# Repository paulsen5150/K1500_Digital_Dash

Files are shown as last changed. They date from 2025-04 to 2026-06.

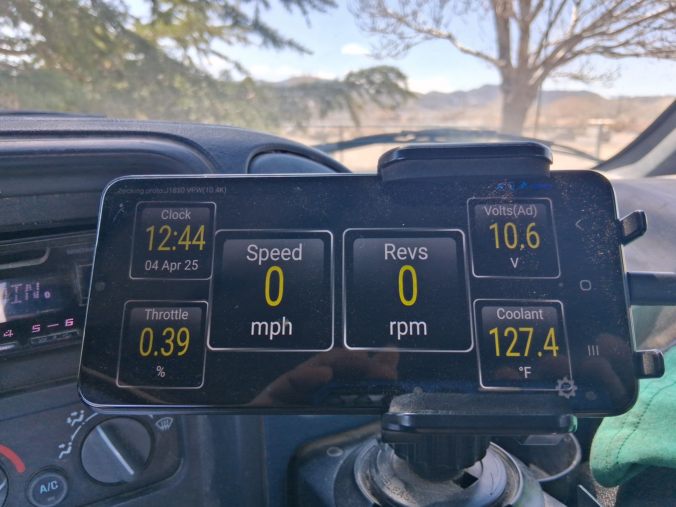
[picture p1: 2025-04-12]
Images/20250404_124431.jpg

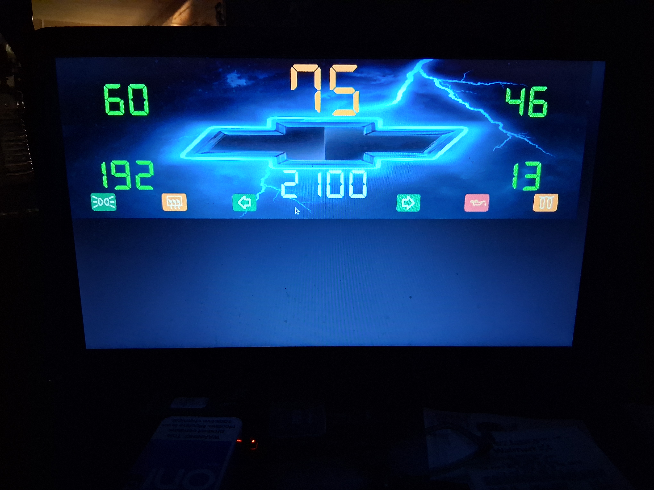
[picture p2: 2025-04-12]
Images/20250406_003022.jpg

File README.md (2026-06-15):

# KITT Master Design Document
## Revision 2.0

### Project
K1500 Integrated Truck Technology (KITT)

Vehicle: 1996 Chevrolet K1500 Extended Cab
Owner: Michael Paulsen

# Executive Summary

KITT is a long-term modernization effort transforming a 1996 Chevrolet K1500 into a modular software-defined vehicle platform. The project centers around an ESP32-S3 vehicle interface controller, an Orange Pi 5 Plus vehicle control computer, a 12.3-inch digital instrument cluster, a future center touchscreen display, advanced diagnostics, HVAC automation, multimedia integration, and a future offline AI assistant.

# System Architecture

Vehicle Interface Layer
- ESP32-S3 DevKitC-1 N16
- ADS1115
- MCP23017
- FRAM
- PC837 Optocouplers

Vehicle Control Layer
- Orange Pi 5 Plus (Confirmed)

Human Interface Layer
- 12.3-inch Digital Instrument Cluster
- 10-inch Center Touchscreen (Under Evaluation)
- Voice Interface

# Dashboard System

Primary Display
- 12.3-inch LCD instrument cluster
- Speedometer
- Tachometer
- Fuel
- Oil Pressure
- Coolant Temperature
- Warnings
- Vehicle Status

Future Center Display
- HVAC
- Navigation
- Audio
- Diagnostics
- Camera Views
- AI Interaction

# Communications Architecture

Priority Order
1. Ethernet (Preferred)
2. Isolated CANBUS (Under Evaluation)
3. USB Serial (Fallback)
4. WiFi (Testing/Beta Only)

WiFi is presently used as an electrical isolation layer during development to protect the SBC from prototype hardware faults.

# Sensor Systems

Analog Inputs
- Fuel Level
- Engine Coolant Temperature
- Oil Pressure

Digital Inputs
- Left Turn
- Right Turn
- High Beam
- Fog Lamps
- Brake Warning
- Check Engine
- Alternator Warning
- Oil Warning
- Illumination

Pulse Inputs
- Vehicle Speed Sensor
- Tachometer

# Odometer System

Status: Implemented

Storage Medium
- FRAM

Method
- 400 VSS Pulses = 0.1 Mile

# HVAC System

Confirmed Hardware
- SyRen 50 Motor Controller

Planned Sensors
- Cabin Temperature
- Ambient Temperature
- Evaporator Temperature

# Audio System

Objectives
- DSP Processing
- Voice Feedback
- Navigation Prompts
- Vehicle Alerts
- 4.1 Channel System

# Camera System

Current
- Rear Camera Planning

Future
- 360 Degree Camera System
- Bird's Eye View
- Parking Assistance
- Trailer Hookup Assistance

# Artificial Intelligence System

Objectives
- Voice-First Vehicle Operation
- Diagnostics
- Navigation
- HVAC Control
- Audio Control
- Predictive Maintenance

Historical Data Analysis
The AI will compare current operating conditions against historical baselines to identify abnormal trends and developing faults.

# Confirmed Hardware

- ESP32-S3 DevKitC-1 N16
- Orange Pi 5 Plus
- ADS1115
- MCP23017
- FRAM
- PC837 Optocouplers
- SyRen 50

# Hardware Under Evaluation

- 10-inch Center Touchscreen
- CANBUS Communications
- Final Connector System
- Final Audio Hardware
- 360 Degree Camera System

# Rejected Hardware / Approaches

- Raspberry Pi as Primary SBC
- WiFi as Permanent Communications Backbone
- Fully Isolated Analog Ground Architecture

# Development Status

Implemented
- Interface PCB
- FRAM Integration
- VSS Hardware
- Tach Hardware
- Sensor Acquisition

In Progress
- Firmware Debugging
- Communications Testing
- Dashboard Software

# Documentation Policy

Authoritative Project File:
KITT_Master_Design_Document.md

Update When:
- Hardware selected
- Hardware rejected
- Architecture changes
- Major features added
- Milestones completed

Revision Format:
v2.0 Initial Master Document
v2.1 Orange Pi Confirmed
v2.2 CANBUS Added
v2.3 Center Display Selected

# Vision Statement

Create a reliable, modular, expandable vehicle computing platform capable of evolving for years while preserving the character and serviceability of the 1996 Chevrolet K1500.

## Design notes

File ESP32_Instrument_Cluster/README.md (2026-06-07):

# ESP32 Instrument Cluster

CircuitPython digital instrument cluster for the ESP32-S3 K1500/KITT interface.

Copy `code.py` to the CircuitPython board root as `code.py`.

## Maintenance Rule

For every future change to `code.py`, add one short dated sentence to the
`# Change log:` block at the top of `code.py` before committing.

## Main Screen

- Landscape 320x240 ST7789 layout
- Large digital MPH and RPM
- Fuel, coolant temp, oil pressure, PRNDL
- Indicator/warning lamp rows
- Bottom-center digital odometer

The page button cycles from the cluster screen to diagnostic pages for
indicators, analog inputs, VSS/tach/odometer, and system status.

## Important Constants

At the top of `code.py`:

- `VSS_PULSES_PER_MILE = 4000`
- `VSS_PULSES_PER_TENTH_MILE = 400`
- `TACH_PULSES_PER_REV = 2.0`
- `ODOMETER_START_TENTHS = 2530000`
- `ODOMETER_START_REMAINDER_PULSES = 0`
- `ODOMETER_SAVE_INTERVAL_SECONDS = 60.0`

The analog sender conversions are placeholders and should be adjusted after
bench or vehicle testing.

## Odometer Storage

The odometer is stored in the MB85RC256V FRAM module at I2C address `0x50`.
The code stores two FRAM records with a magic header, sequence number, odometer
tenths, remainder pulses, and checksum, then loads the newest valid record on
startup.

`tenths` is the total completed 0.1-mile count. `remainder_pulses` is the VSS
pulse count since the last completed 0.1 mile. On startup, the app resumes from
both values so it continues toward the next tenth-mile increment.

The app saves periodically while tach is active and saves once when tach becomes
stale, which is treated as engine shutdown.

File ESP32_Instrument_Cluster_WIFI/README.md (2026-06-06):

# ESP32 Instrument Cluster WiFi

CircuitPython ESP32-S3 instrument cluster with a built-in WiFi access point and
HTTP telemetry server for laptop viewing.

This version is based on `ESP32_Instrument_Cluster/code.py`. It keeps the
display, sensor polling, odometer, diagnostic pages, and serial JSON output,
then adds:

- ESP32 access point mode
- Browser dashboard at `/`
- Machine-readable JSON at `/data.json`
- Health/status JSON at `/health.json`

## Board Setup

Copy `code.py` to the CircuitPython board root as `/code.py`.

Install the same libraries required by the original cluster, plus:

- `adafruit_httpserver.mpy`

The existing hardware libraries are still required:

- `adafruit_display_text`
- `adafruit_ads1x15`
- `adafruit_pcf8574`
- `adafruit_st7789`
- `fourwire`

## WiFi Settings

The code has defaults, so `settings.toml` is optional. To customize the AP name,
password, channel, or port, copy `settings.example.toml` to the board root as
`/settings.toml` and edit it.

Defaults:

```toml
DASH_AP_SSID = "K1500_Dash"
DASH_AP_PASSWORD = "k1500dash"
DASH_AP_CHANNEL = "6"
DASH_HTTP_PORT = "5000"
```

Port `5000` is used to avoid conflicting with CircuitPython Web Workflow on
port `80`.

## Laptop Use

1. Boot the ESP32.
2. Connect the laptop WiFi to `K1500_Dash`.
3. Open the URL shown on the ESP32 system page or serial console.

Common default URL:

```text
http://192.168.4.1:5000/
```

Useful endpoints:

```text
http://192.168.4.1:5000/
http://192.168.4.1:5000/data.json
http://192.168.4.1:5000/health.json
```

For terminal testing from the laptop:

```bash
python3 laptop_poll_dash.py
```

Run that script from this directory after connecting the laptop to the ESP32 AP.

## Notes

If the HTTP server library is missing or WiFi setup fails, the dash still runs.
The error is reported on the system diagnostic page and in the serial JSON under
the `wifi` key.

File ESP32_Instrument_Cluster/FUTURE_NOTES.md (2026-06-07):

# Future Revision Notes

- Add a one-time odometer set mode for matching the truck's actual mileage:
  `ODOMETER_FORCE_SET`, `ODOMETER_FORCE_TENTHS`, and
  `ODOMETER_FORCE_REMAINDER_PULSES`. Boot once with force set enabled to write
  the target mileage to FRAM, then disable it before normal use.
- Confirm final VSS calibration. Current default is `VSS_PULSES_PER_MILE = 4000`
  and `VSS_PULSES_PER_TENTH_MILE = 400`.
- Confirm final tach calibration. Current default is `TACH_PULSES_PER_REV = 2.0`.
- Replace placeholder fuel, oil pressure, and coolant sender conversions with
  tested sender curves.
- After hardware display testing, adjust the cluster layout for readability,
  spacing, and lamp placement on the physical ST7789 screen.
- PRNDL should display only the current gear selected as decoded by the logic
  table. Examples: when in Park display `P` or `PARK`; Reverse display `R` or
  `REV`; Overdrive/Drive display `OD` or `D`; lower gears display `3`, `2`, or
  `1`.
- Remove captions from idiot lights and odometer.
- Consider replacing text-only idiot lights with small bitmap icons once the
  main layout is proven on hardware.

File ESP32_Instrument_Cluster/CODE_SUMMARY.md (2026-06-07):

#06/07/2026
# code.py Summary

`code.py` is a CircuitPython instrument-cluster application for an ESP32-S3.
It reads the K1500/KITT interface hardware, converts the raw signals into dash
values, drives a 320x240 ST7789 LCD, tracks odometer distance, and cycles
between a graphical cluster page and diagnostic text pages.

## Hardware Interfaces

- I2C runs on `board.IO9` SCL and `board.IO8` SDA.
- PCF8574 at `0x20` reads indicator and PRNDL inputs.
- PCF8574 at `0x21` reads warning-light inputs.
- MB85RC256V FRAM at `0x50` stores odometer tenths and remainder pulses.
- ADS1115 at `0x48` reads analog channels:
  - `ECT` on ADS channel 0
  - `OilPres` on ADS channel 1
  - `Fuel` on ADS channel 2
  - `ADS3` on ADS channel 3
- ST7789 LCD uses SPI pins `IO12`, `IO11`, `IO10`, `IO13`, `IO14`, and
  backlight pin `IO21`.
- Page button uses `IO17`.
- VSS pulse input uses `IO15`.
- Tach pulse input uses `IO16`.

FRAM Found I2C device at 0x50

## Data Collection

- `DirectPCF8574` reads each PCF8574 device as a raw byte over I2C, then
  `read_signal_group()` decodes configured bits into raw and active states.
- Indicator signals include high beam, turn signals, seat belt, and PRNDL
  switch bits. High beam, turn signals, and seat belt are active-low.
- Warning signals include ABS, alternator, air bag, DRL, MIL, park brake, and
  two spare warning inputs. These are active-low.
- `read_ads_channels()` reads ADS1115 voltage and converts it into estimated
  sender resistance.
- Fuel percent and oil pressure scale directly from sender resistance.
- Coolant temperature is interpolated from the `GM_ECT_TABLE` resistance table.
- `PulseCounter` counts falling-edge pulses for VSS and tach, calculates
  frequency over a one-second window, and reports stale pulse state.

## Derived Values

- Speed is calculated from VSS frequency using `VSS_PULSES_PER_MILE`.
- RPM is calculated from tach frequency using `TACH_PULSES_PER_REV`.
- PRNDL is decoded from four PRNDL indicator bits using `PRNDL_TABLE`.
- Derived warnings are calculated for:
  - low fuel
  - low oil pressure
  - high coolant temperature
  - stale VSS signal
  - stale tach signal

## Odometer

- `Odometer` stores distance as tenths of a mile plus remainder pulses.
- It loads and saves odometer data in MB85RC256V FRAM instead of using
  `/odometer.json`.
- It stores two FRAM records with a magic header, sequence number, tenths,
  remainder pulses, and checksum, then loads the newest valid record at boot.
- It starts from `253000.0` miles if no valid FRAM odometer record is available.
- It periodically saves while the engine is running and saves once after the
  tach signal becomes stale following prior engine activity.

## Display

- `ClusterPage` is the main graphical display page. It shows:
  - speed
  - RPM
  - fuel percent
  - coolant temperature
  - oil pressure
  - PRNDL
  - odometer
  - indicator and warning lamps
- `TextPage` displays diagnostic pages for:
  - indicators and warnings
  - ADS1115 analog readings
  - VSS, tach, and odometer details
  - system status
- `DisplayController` switches between the graphical page and text pages.
- The main graphical page refreshes every `DISPLAY_INTERVAL`; text pages use
  `TEXT_DISPLAY_INTERVAL`.
- Garbage collection is run around page switches and text-page updates to reduce
  memory pressure on the ESP32-S3.

## Main Loop

The main loop continuously:

1. Tracks loop frequency.
2. Updates VSS and tach pulse counters.
3. Adds VSS pulses to the odometer.
4. Handles page-button debounce and page changes.
5. Polls PCF8574 inputs.
6. Polls ADS1115 analog channels.
7. Updates pulse snapshots, cluster values, derived warnings, and odometer state.
8. Saves odometer data when needed.
9. Refreshes the display at the page-specific interval.
10. Prints memory and loop-rate debug output once per second.

## Notes

- The file currently contains no WiFi, access-point, HTTP server, or laptop
  telemetry features.
- Serial JSON output via `snapshot_for_serial()` still exists but is currently
  commented out in the main loop in favor of memory and loop-rate debug prints.

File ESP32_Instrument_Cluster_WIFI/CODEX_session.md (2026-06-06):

# Codex Session Log: ESP32 Instrument Cluster WiFi

Date: 2026-05-27

## User Request

Create a new version based on `ESP32_Instrument_Cluster/code.py` in a new
directory named `ESP32_Instrument_Cluster_WIFI`, with the ability to transmit
dash data by WiFi to a laptop.

## Planning Decisions

After inspecting the existing CircuitPython cluster code and related serial
testbed scripts, Codex identified that the existing app already builds a single
live `state` object and prints a JSON snapshot over serial. That state snapshot
was chosen as the source for WiFi telemetry.

User selected:

- WiFi mode: ESP32 hotspot/access point
- Laptop access style: ESP web server

Implementation plan:

- Copy the existing cluster app into a new `ESP32_Instrument_Cluster_WIFI`
  directory.
- Keep the original display, sensor polling, odometer, diagnostic pages, and
  serial JSON behavior intact.
- Add AP mode using CircuitPython `wifi.radio.start_ap(...)`.
- Add an HTTP server using `socketpool` and `adafruit_httpserver`.
- Serve:
  - `/` as a small browser dashboard
  - `/data.json` as live telemetry JSON
  - `/health.json` as WiFi/server health JSON
- Add WiFi/server status to the existing system diagnostic page.
- Add setup documentation and a laptop polling script.

## Files Created

- `ESP32_Instrument_Cluster_WIFI/code.py`
- `ESP32_Instrument_Cluster_WIFI/README.md`
- `ESP32_Instrument_Cluster_WIFI/settings.example.toml`
- `ESP32_Instrument_Cluster_WIFI/laptop_poll_dash.py`
- `ESP32_Instrument_Cluster_WIFI/CODEX_session.md`

## Implementation Summary

`code.py` was copied from `ESP32_Instrument_Cluster/code.py` and updated with:

- Optional imports for:
  - `wifi`
  - `socketpool`
  - `adafruit_httpserver`
- Settings read from `settings.toml` via `os.getenv()`:
  - `DASH_AP_SSID`
  - `DASH_AP_PASSWORD`
  - `DASH_AP_CHANNEL`
  - `DASH_HTTP_PORT`
- Default settings:
  - SSID: `K1500_Dash`
  - Password: `k1500dash`
  - Channel: `6`
  - HTTP port: `5000`
- A `WiFiTelemetry` class that:
  - starts the ESP32 AP
  - creates a `socketpool.SocketPool`
  - starts an `adafruit_httpserver.Server`
  - registers `/`, `/data.json`, and `/health.json`
  - calls `server.poll()` from the main loop
  - reports errors without stopping the dash app
- The system diagnostic page now shows WiFi status and the HTTP URL.
- The serial JSON snapshot now includes the `wifi` key.

The browser dashboard at `/` polls `/data.json` once per second and displays:

- MPH
- RPM
- PRNDL
- Fuel
- Oil pressure
- Coolant temperature
- Odometer
- Raw JSON

`laptop_poll_dash.py` is a normal laptop-side Python script that fetches:

```text
http://192.168.4.1:5000/data.json
```

and prints selected dash fields once per second.

## Verification

Codex ran:

```bash
python3 -m py_compile ESP32_Instrument_Cluster_WIFI/code.py ESP32_Instrument_Cluster_WIFI/laptop_poll_dash.py
```

The syntax check passed.

Codex removed the generated `__pycache__` afterward.

Hardware WiFi/AP behavior was not tested in this session because the ESP32 board
was not available through the local environment.

## Usage Notes

To use the WiFi version:

1. Copy `ESP32_Instrument_Cluster_WIFI/code.py` to the CircuitPython board as
   `/code.py`.
2. Install the original cluster libraries plus `adafruit_httpserver.mpy`.
3. Optionally copy `settings.example.toml` to the board root as
   `/settings.toml` and edit the values.
4. Boot the ESP32.
5. Connect the laptop to the ESP32 AP, default `K1500_Dash`.
6. Open:

```text
http://192.168.4.1:5000/
```

or read raw telemetry from:

```text
http://192.168.4.1:5000/data.json
```

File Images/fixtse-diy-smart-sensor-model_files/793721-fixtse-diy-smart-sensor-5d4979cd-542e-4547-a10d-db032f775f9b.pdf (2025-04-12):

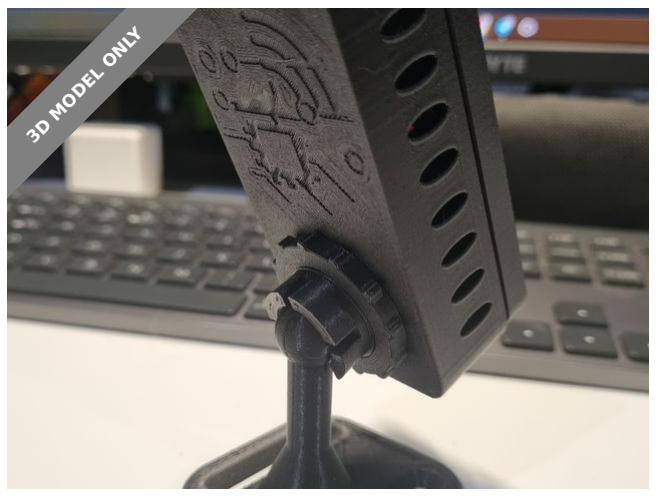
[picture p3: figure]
3D MODEL ONLY

## Summary

This case is designed to house an HLK-LD2450 mmWave Radar Sensor and an ESP32 30-pin board. No soldering skills needed

Hobby & Makers (https://printables.com/model?categoryId=48) > Electronics (https://printables.com/model?categoryId=52)

This remix of the esp32-wroom case (https://www.printables.com/es/model/579266-esp32-wroom-case-temp-and-mmwave-dht11-ld2410) and the everything presence lite (https://www.printables.com/es/model/624830-everything-presence-lite-official-case) it's a versatile, pressure-fit wonder, requiring zero soldering or specialized tools; just snap that ESP32 Board together with the HLK-LD2450 sensor.
Then, flash it with ESPHome using our custom firmware, and voilà – you've created the foundation for your smart sensor!

With enough space left in the case, you can effortlessly expand its capabilities by incorporating a microphone, light sensor, temperature sensor, air quality sensor, or any other sensor that you want.

Printed with PLA, 40% infill.

Watch the full tutorial here: https://fixtse.com/blog/esphome-mmwave-sensor (https://fixtse.com/blog/esphome-mmwave-sensor)

You can buy the devices used in the project here:

Using the affiliate links below helps support all the content I create.

ESP32 30 PIN Development Board
Amazon: (3 pack) (https://amzn.to/3V4J5Q2)

fixtSE (https://printables.com/@Fixt_439752)

## fixtSE DIY Smart Sensor

VIEW IN BROWSER (https://printables.com/model/793721-fixtse-diy-smart-sensor)

updated 21. 3. 2024 | published 21. 3. 2024

•
◦

## Model files

Aliexpress: (USB C / Micro USB) (https://s.click.aliexpress.com/e/_DBI6JUH) HLK-LD2450 mmWave Radar Sensor Amazon: (HLK-LD2450 (https://amzn.to/4c9Oawp) Kit)
Aliexpress: (HLK-LD2450 Kit) Option 1 (https://s.click.aliexpress.com/e/_Dnl1OJf)
Option 2 (https://s.click.aliexpress.com/e/_DdPanCz)

Optional

Dupont Cable
Amazon: (Dupont Cable Female to female) (https://amzn.to/49VSQEr) Aliexpress: (Dupont Cable Female to female) (https://s.click.aliexpress.com/e/_Ddv5mrB) USB C Cable
Amazon: (2 Pack) (https://amzn.to/3To9Nll)
Aliexpress: (USB C Cable) (https://s.click.aliexpress.com/e/_DB7nkS5)
5v charger
Amazon: (2 Pack) (https://amzn.to/432N2Xi)
Aliexpress: (5v charger) (https://s.click.aliexpress.com/e/_DdcRX5R)

If you plan on adding a light sensor in the future, print the case in white (black reduces the light captured by the sensor, so it will report lower values)

## This remix is based on

Everything Presence Lite - Official Case (https://printables.com/model/624830-everything-presence-lite-official-case) by Everything Smart Home (https://printables.com/@EverythingSma_335412)

esp32-wroom case - Temp and mmWave - DHT11 LD2410 (https://printables.com/model/579266-esp32-wroom-case-temp-and-mmwave-dht11-ld2410)
by djc3d (https://printables.com/@djc3d_1046749)

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
body.stl

## License

This work is licensed under a
Creative Commons (4.0 International License)

Attribution-NonCommercial (http://creativecommons.org/licenses/by-nc/4.0/)

✖ | Sharing without ATTRIBUTION
✔ | Remix Culture allowed
✖ | Commercial Use
✖ | Free Cultural Works
✖ | Meets Open Definition

esp32_housing.stl

esp32_lid.stl

joint.stl

base.stl

locknut.stl

body_light_temperature.stl

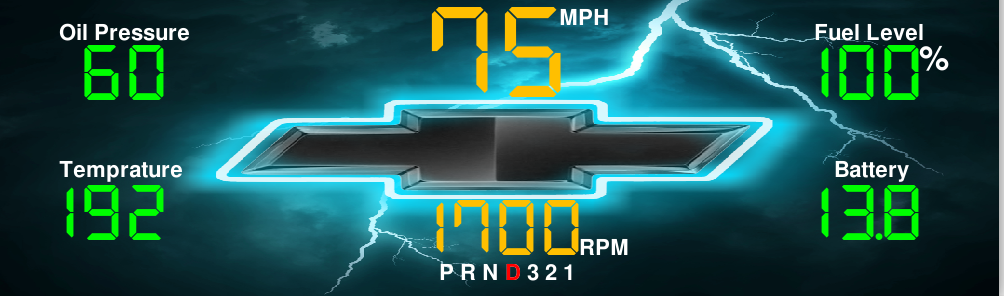
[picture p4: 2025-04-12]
Images/Screenshot from 2025-04-06 17-31-42.png

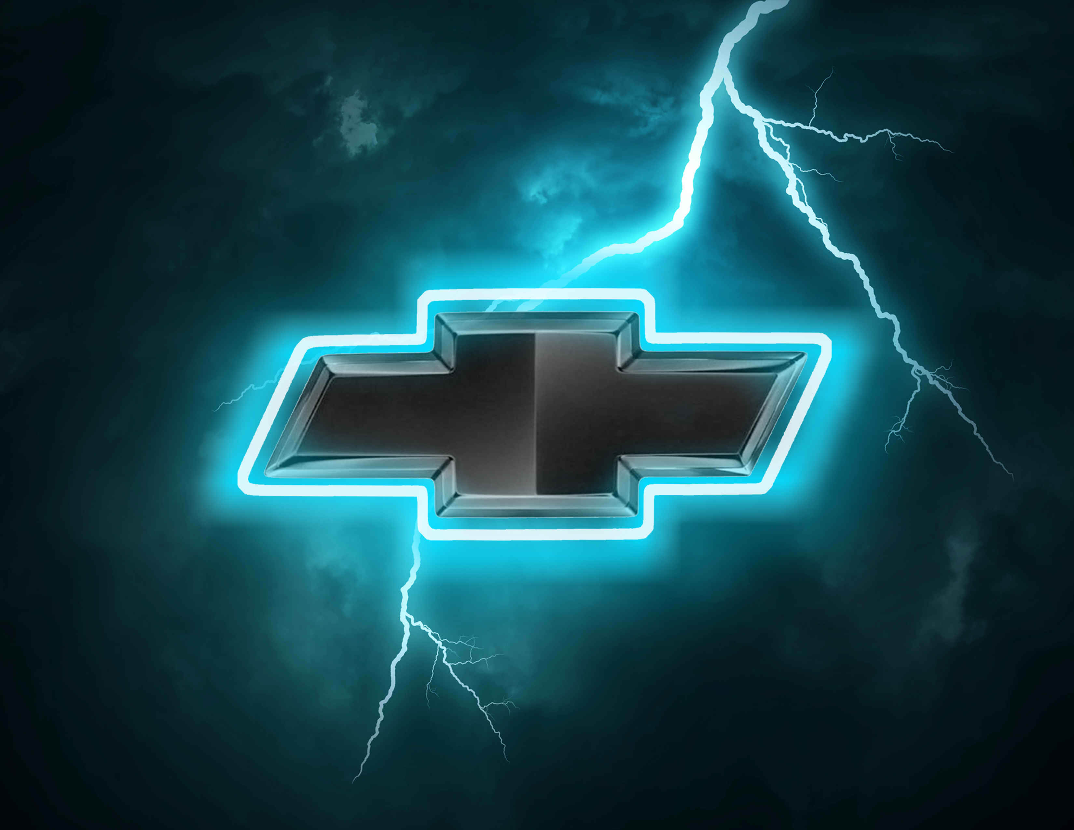
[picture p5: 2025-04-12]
Images/Bowtie_Lightning_Emblem.png

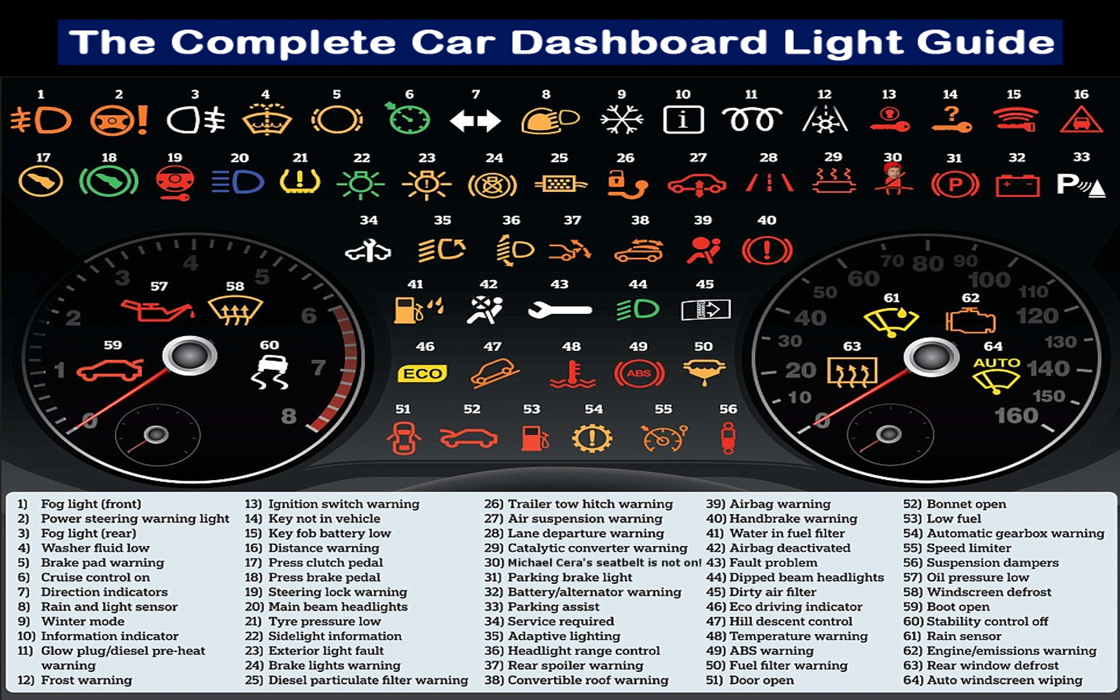
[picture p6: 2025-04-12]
Images/263d9ffc7c592138f45370a9a1bfe4f3.png

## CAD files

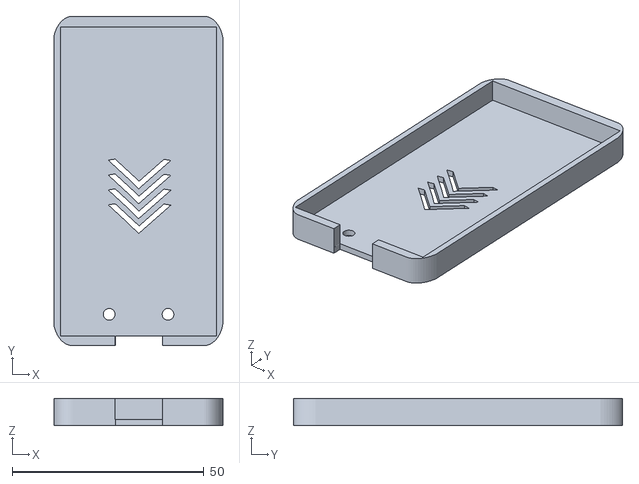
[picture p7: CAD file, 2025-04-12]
Images/fixtse-diy-smart-sensor-model_files/esp32_lid.stl
44.0 x 85.7 x 7.10

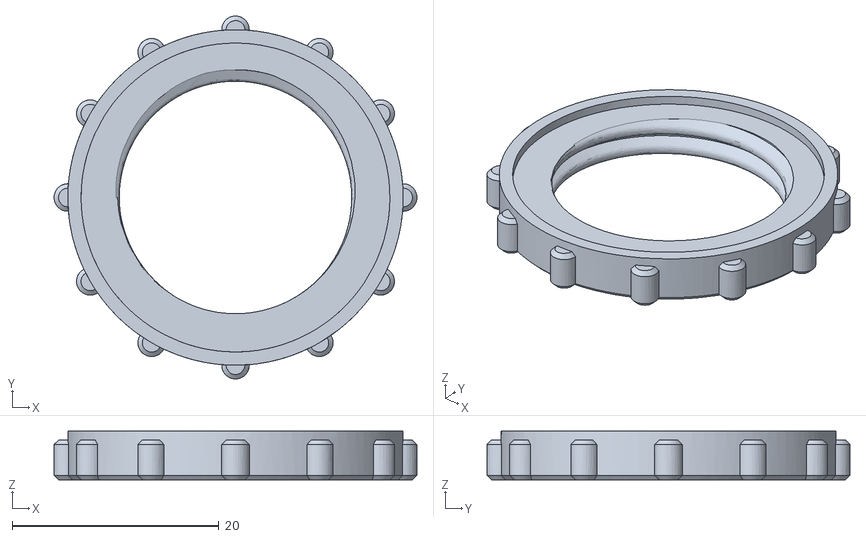
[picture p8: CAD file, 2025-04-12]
Images/fixtse-diy-smart-sensor-model_files/locknut.stl
35.1 x 35.1 x 4.71

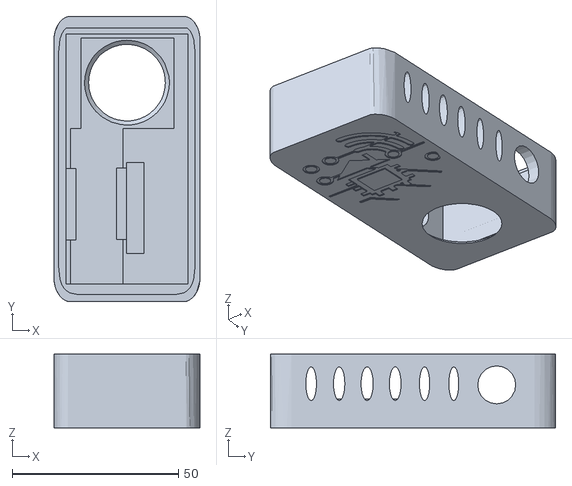
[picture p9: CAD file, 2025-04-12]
Images/fixtse-diy-smart-sensor-model_files/body_light_temperature.stl
43.9 x 85.7 x 22.1

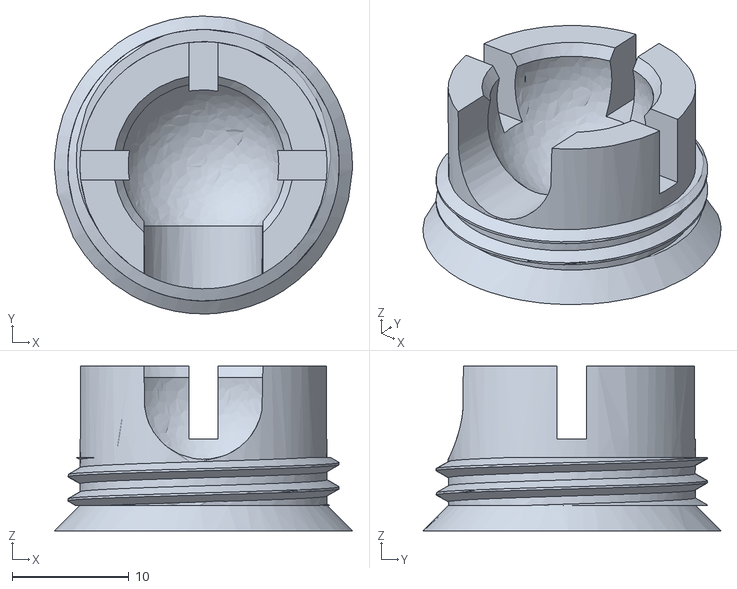
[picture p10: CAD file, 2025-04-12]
Images/fixtse-diy-smart-sensor-model_files/joint.stl
25.6 x 25.6 x 14.1

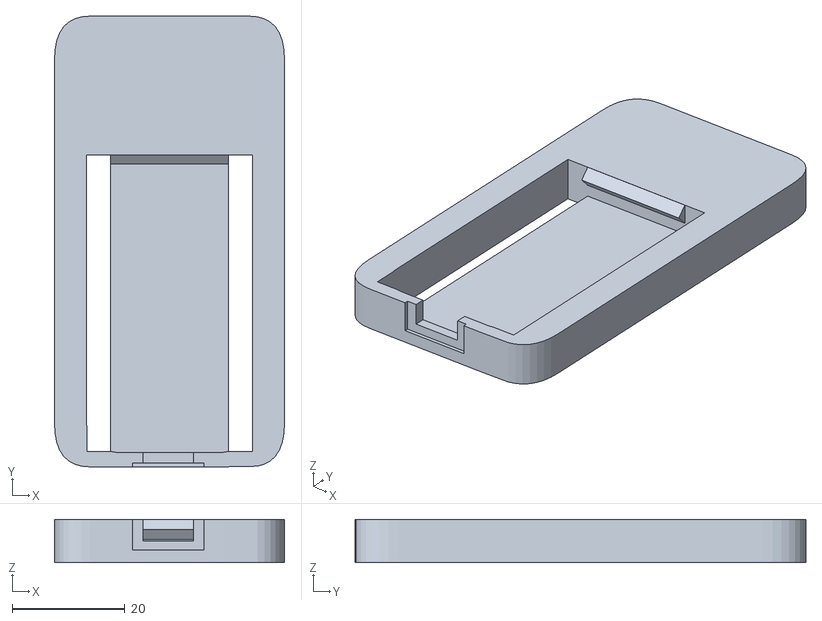
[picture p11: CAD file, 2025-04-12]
Images/fixtse-diy-smart-sensor-model_files/esp32_housing.stl
40.8 x 80.0 x 7.71

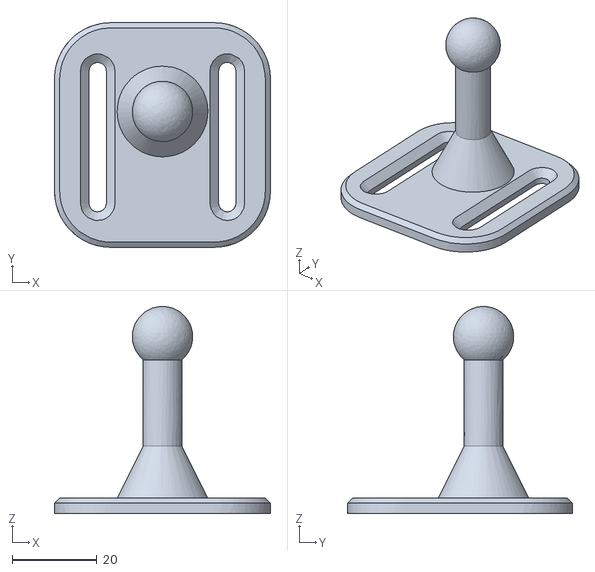
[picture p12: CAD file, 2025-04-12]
Images/fixtse-diy-smart-sensor-model_files/base.stl
51.0 x 53.0 x 48.9

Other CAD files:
Images/fixtse-diy-smart-sensor-model_files/body.stl

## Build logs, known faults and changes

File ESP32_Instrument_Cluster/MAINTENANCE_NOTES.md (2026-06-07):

# Maintenance Notes

## code.py Change Log Rule

For every future change to `code.py`, add one short dated sentence to the
`# Change log:` block at the top of `code.py` before committing.

Use this format:

```python
# YYYY-MM-DD: Short description of what changed.
```

Keep entries concise and focused on behavior, hardware support, or diagnostics.

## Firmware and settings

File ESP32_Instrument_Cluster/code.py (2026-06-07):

# Change log:
# 2026-06-07: Added a persistent rule to record future code.py changes here.

"""
Reads the interface board and display a graphical output on 2inch lcd

ESP32-S3 CircuitPython instrument cluster for the K1500/KITT interface.

This version keeps the hardware setup from ESP32_KITT_Display/code.py, but the
default page is a landscape digital instrument cluster with speed, RPM, analog
gauges, warning lamps, PRNDL, and an integer-backed odometer.
"""
import gc
import json
import time

import board
import busio
import digitalio
import displayio
import terminalio
from adafruit_display_text import label
import adafruit_ads1x15.ads1115 as ADS
from adafruit_ads1x15.analog_in import AnalogIn
import adafruit_st7789
import fourwire


# Hardware configuration
I2C_SCL = board.IO9
I2C_SDA = board.IO8

PCF_INDICATOR_ADDRESS = 0x20
PCF_WARNING_ADDRESS = 0x21
ADS_ADDRESS = 0x48
FRAM_ADDRESS = 0x50

TFT_SCK = board.IO12
TFT_MOSI = board.IO11
TFT_CS = board.IO10
TFT_DC = board.IO13
TFT_RST = board.IO14
TFT_BL = board.IO21
TFT_WIDTH = 320
TFT_HEIGHT = 240
TFT_ROTATION = 90

PAGE_BUTTON_PIN = board.IO17
VSS_PIN = board.IO15
TACH_PIN = board.IO16

#COMMENTED OUT FOR DEBUGGING 06/06/2026
#REVERTED TO ORIGINAL 06/07/2026
PCF_POLL_INTERVAL = 0.05
ADS_POLL_INTERVAL = 0.2
PULSE_POLL_INTERVAL = 0.001
DISPLAY_INTERVAL = 0.1
TEXT_DISPLAY_INTERVAL = 0.5
SERIAL_INTERVAL = 1.0

BUTTON_DEBOUNCE = 0.05
FREQUENCY_WINDOW = 1.0
STALE_PULSE_SECONDS = 2.0
ENGINE_OFF_TACH_STALE_SECONDS = 5.0

#TIMING CHANGED FOR DEBUGGING 06/06/2026
#REVERTED TO ORIGINAL 06/07/2026
# SERIAL_INTERVAL = 10.0
# DISPLAY_INTERVAL = 0.5
# TEXT_DISPLAY_INTERVAL = 1.0
# PCF_POLL_INTERVAL = 0.2
# ADS_POLL_INTERVAL = 0.5
# PULSE_POLL_INTERVAL = 0.01


# Calibration placeholders. Adjust these after road/bench testing.
VSS_PULSES_PER_MILE = 4000
VSS_PULSES_PER_TENTH_MILE = 400
TACH_PULSES_PER_REV = 2.0

ODOMETER_START_TENTHS = 2530000
ODOMETER_START_REMAINDER_PULSES = 0
ODOMETER_SAVE_INTERVAL_SECONDS = 60.0
ODOMETER_FRAM_SLOT_SIZE = 16
ODOMETER_FRAM_SLOTS = (0, ODOMETER_FRAM_SLOT_SIZE)
ODOMETER_FRAM_MAGIC = b"ODO1"

SUPPLY_VOLTAGE = 3.3
SENDER_PULLUP_OHMS = 250.0
MAX_SENDER_OHMS = 90.0
MAX_OIL_PSI = 80.0
MAX_COOLANT_F = 260.0

GM_ECT_TABLE = (
    (-40.0, 100700.0),
    (-22.0, 52700.0),
    (-4.0, 28680.0),
    (14.0, 16180.0),
    (32.0, 9420.0),
    (50.0, 5670.0),
    (68.0, 3520.0),
    (86.0, 2238.0),
    (104.0, 1459.0),
    (122.0, 973.0),
    (140.0, 667.0),
    (158.0, 467.0),
    (176.0, 332.0),
    (194.0, 241.0),
    (212.0, 177.0),
)

LOW_FUEL_PERCENT = 12.5
LOW_OIL_PSI = 5.0
HIGH_COOLANT_F = 230.0


COLOR_BG = 0x000000
COLOR_DIM = 0x303030
COLOR_TEXT = 0xE8E8E8
COLOR_MUTED = 0x808080
COLOR_GREEN = 0x00FF66
COLOR_AMBER = 0xFFAA00
COLOR_RED = 0xFF2020
COLOR_BLUE = 0x2080FF


INDICATOR_SIGNALS = (
    {"name": "HiBeam", "bit": 0, "active_high": False},
    {"name": "L Turn", "bit": 1, "active_high": False},
    {"name": "R Turn", "bit": 2, "active_high": False},
    {"name": "SeatBelts", "bit": 3, "active_high": False},
    {"name": "PRNDL P", "bit": 4, "active_high": True},
    {"name": "PRNDL C", "bit": 5, "active_high": True},
    {"name": "PRNDL B", "bit": 6, "active_high": True},
    {"name": "PRNDL A", "bit": 7, "active_high": True},
)

WARNING_SIGNALS = (
    {"name": "ABS", "bit": 0, "active_high": False},
    {"name": "ALT", "bit": 1, "active_high": False},
    {"name": "AirBag", "bit": 2, "active_high": False},
    {"name": "DRL", "bit": 3, "active_high": False},
    {"name": "MIL", "bit": 4, "active_high": False},
    {"name": "ParkBrake", "bit": 5, "active_high": False},
    {"name": "Spare1", "bit": 6, "active_high": False},
    {"name": "Spare2", "bit": 7, "active_high": False},
)

ADS_CHANNELS = (
    {"name": "ECT", "channel": 0},
    {"name": "OilPres", "channel": 1},
    {"name": "Fuel", "channel": 2},
    {"name": "ADS3", "channel": 3},
)

PRNDL_TABLE = {
    (False, True, True, False): "P",
    (False, False, True, True): "R",
    (True, False, True, False): "N",
    (True, False, False, True): "OD",
    (False, False, False, False): "3",
    (False, True, False, True): "2",
    (True, True, False, False): "1",
}


class NullDisplay:
    def show(self, group):
        pass

    @property
    def root_group(self):
        return None

    @root_group.setter
    def root_group(self, group):
        pass


def pin_name(pin):
    return str(pin).split(".")[-1]


def init_i2c():
    i2c_bus = busio.I2C(I2C_SCL, I2C_SDA)
    while not i2c_bus.try_lock():
        time.sleep(0.01)
    try:
        found = tuple(i2c_bus.scan())
    finally:
        i2c_bus.unlock()
    return i2c_bus, found


class DirectPCF8574:
    def __init__(self, i2c_bus, address):
        self.i2c_bus = i2c_bus
        self.address = address
        self._buffer = bytearray(1)
        self._last_value = 0xFF
        self.write_byte(0xFF)

    def _lock(self):
        start = time.monotonic()
        while not self.i2c_bus.try_lock():
            if time.monotonic() - start > 0.25:
                raise RuntimeError("I2C lock timeout")
            time.sleep(0.001)

    def write_byte(self, value):
        self._lock()
        try:
            self.i2c_bus.writeto(self.address, bytes((value & 0xFF,)))
        finally:
            self.i2c_bus.unlock()

    def read_byte(self):
        self._lock()
        try:
            self.i2c_bus.readfrom_into(self.address, self._buffer)
        finally:
            self.i2c_bus.unlock()
        self._last_value = self._buffer[0]
        return self._last_value


class DirectFRAM:
    def __init__(self, i2c_bus, address):
        self.i2c_bus = i2c_bus
        self.address = address
        self._address_buffer = bytearray(2)

    def _lock(self):
        start = time.monotonic()
        while not self.i2c_bus.try_lock():
            if time.monotonic() - start > 0.25:
                raise RuntimeError("I2C lock timeout")
            time.sleep(0.001)

    def _set_address(self, memory_address):
        self._address_buffer[0] = (memory_address >> 8) & 0xFF
        self._address_buffer[1] = memory_address & 0xFF

    def read(self, memory_address, length):
        buffer = bytearray(length)
        self._lock()
        try:
            self._set_address(memory_address)
            self.i2c_bus.writeto_then_readfrom(
                self.address,
                self._address_buffer,
                buffer,
            )
        finally:
            self.i2c_bus.unlock()
        return buffer

    def write(self, memory_address, data):
        buffer = bytearray(2 + len(data))
        buffer[0] = (memory_address >> 8) & 0xFF
        buffer[1] = memory_address & 0xFF
        buffer[2:] = data
        self._lock()
        try:
            self.i2c_bus.writeto(self.address, buffer)
        finally:
            self.i2c_bus.unlock()


def init_pcf(i2c_bus, address):
    try:
        return DirectPCF8574(i2c_bus, address), None
    except Exception as exc:
        return None, str(exc)


def init_fram(i2c_bus, address):
    try:
        fram = DirectFRAM(i2c_bus, address)
        fram.read(0, 1)
        return fram, None
    except Exception as exc:
        return None, str(exc)


def init_ads(i2c_bus):
    try:
        ads = ADS.ADS1115(i2c_bus, address=ADS_ADDRESS)
        inputs = {}
        for channel in ADS_CHANNELS:
            inputs[channel["name"]] = AnalogIn(ads, channel["channel"])
        return ads, inputs, None
    except Exception as exc:
        return None, {}, str(exc)


def init_display():
    try:
        displayio.release_displays()
        spi = busio.SPI(TFT_SCK, MOSI=TFT_MOSI)
        display_bus = fourwire.FourWire(
#        display_bus = displayio.FourWire(
            spi,
            command=TFT_DC,
            chip_select=TFT_CS,
            reset=TFT_RST,
        )
        display = adafruit_st7789.ST7789(
            display_bus,
            width=TFT_WIDTH,
            height=TFT_HEIGHT,
            rotation=TFT_ROTATION,
        )
        backlight = digitalio.DigitalInOut(TFT_BL)
        backlight.direction = digitalio.Direction.OUTPUT
        backlight.value = True
        return display, backlight, None
    except Exception as exc:
        print("Display init failed:", exc)
        return NullDisplay(), None, str(exc)


def make_input(pin):
    dio = digitalio.DigitalInOut(pin)
    dio.direction = digitalio.Direction.INPUT
    dio.pull = digitalio.Pull.UP
    return dio


def read_bit(raw_value, bit):
    if raw_value is None:
        return None
    return bool(raw_value & (1 << bit))


def decode_signal(raw, active_high):
    if raw is None:
        return None
    return raw if active_high else not raw


def read_signal_group(pcf, configs):
    if pcf is None:
        raw_value = None
    else:
        try:
            raw_value = pcf.read_byte()
        except Exception:
            raw_value = None
    values = {}
    for config in configs:
        raw = read_bit(raw_value, config["bit"])
        values[config["name"]] = {
            "raw": raw,
            "active": decode_signal(raw, config["active_high"]),
        }
    return values


def clamp(value, low, high):
    return min(max(value, low), high)


def voltage_to_resistance(voltage):
    if voltage <= 0.0:
        return 0.0
    if voltage >= SUPPLY_VOLTAGE:
        return MAX_SENDER_OHMS
    return (voltage * SENDER_PULLUP_OHMS) / (SUPPLY_VOLTAGE - voltage)


def resistance_to_percent(resistance):
    return clamp(100.0 * (resistance / MAX_SENDER_OHMS), 0.0, 100.0)


def resistance_to_oil_psi(resistance):
    return clamp(MAX_OIL_PSI * (resistance / MAX_SENDER_OHMS), 0.0, MAX_OIL_PSI)


def resistance_to_coolant_f(resistance):
    if resistance >= GM_ECT_TABLE[0][1]:
        return GM_ECT_TABLE[0][0]
    if resistance <= GM_ECT_TABLE[-1][1]:
        return GM_ECT_TABLE[-1][0]
    for index in range(len(GM_ECT_TABLE) - 1):
        low_temp, high_resistance = GM_ECT_TABLE[index]
        high_temp, low_resistance = GM_ECT_TABLE[index + 1]
        if high_resistance >= resistance >= low_resistance:
            span = high_resistance - low_resistance
            position = (high_resistance - resistance) / span
            return low_temp + position * (high_temp - low_temp)
    return None


def read_ads_channels(ads_inputs):
    values = {}
    for channel in ADS_CHANNELS:
        name = channel["name"]
        analog = ads_inputs.get(name)
        if analog is None:
            values[name] = {
                "raw": None,
                "voltage": None,
                "resistance": None,
                "converted": None,
            }
            continue
        try:
            voltage = analog.voltage
            resistance = voltage_to_resistance(voltage)
            converted = None
            if name == "Fuel":
                converted = resistance_to_percent(resistance)
            elif name == "OilPres":
                converted = resistance_to_oil_psi(resistance)
            elif name == "ECT":
                converted = resistance_to_coolant_f(resistance)
            values[name] = {
                "raw": analog.value,
                "voltage": voltage,
                "resistance": resistance,
                "converted": converted,
            }
        except Exception:
            values[name] = {
                "raw": None,
                "voltage": None,
                "resistance": None,
                "converted": None,
            }
    return values


def prndl_state(indicators):
    a = indicators["PRNDL A"]["active"]
    b = indicators["PRNDL B"]["active"]
    c = indicators["PRNDL C"]["active"]
    p = indicators["PRNDL P"]["active"]
    if None in (a, b, c, p):
        return "NO DATA"
    return PRNDL_TABLE.get((a, b, c, p), "INVALID")


class PulseCounter:
    def __init__(self, input_pin, name):
        self.input_pin = input_pin
        self.name = name
        self.last_raw = input_pin.value
        self.count = 0
        self.window_count = 0
        self.frequency = 0.0
        self.last_edge_time = None
        self.last_window_time = time.monotonic()

    def update(self, now):
        edge_count = 0
        raw = self.input_pin.value
        if self.last_raw and not raw:
            self.count += 1
            self.window_count += 1
            edge_count = 1
            self.last_edge_time = now
        self.last_raw = raw

        elapsed = now - self.last_window_time
        if elapsed >= FREQUENCY_WINDOW:
            self.frequency = self.window_count / elapsed
            self.window_count = 0
            self.last_window_time = now
        return edge_count

    def snapshot(self, now, stale_seconds=STALE_PULSE_SECONDS):
        if self.last_edge_time is None:
            age = None
            stale = True
        else:
            age = now - self.last_edge_time
            stale = age > stale_seconds
        return {
            "count": self.count,
            "frequency_hz": self.frequency,
            "last_edge_age": age,
            "stale": stale,
        }


def uint32_to_bytes(value):
    return bytes((
        (value >> 24) & 0xFF,
        (value >> 16) & 0xFF,
        (value >> 8) & 0xFF,
        value & 0xFF,
    ))


def uint16_to_bytes(value):
    return bytes(((value >> 8) & 0xFF, value & 0xFF))


def bytes_to_uint32(data, offset):
    return (
        (data[offset] << 24)
        | (data[offset + 1] << 16)
        | (data[offset + 2] << 8)
        | data[offset + 3]
    )


def bytes_to_uint16(data, offset):
    return (data[offset] << 8) | data[offset + 1]


def odometer_checksum(data):
    return sum(data[:14]) & 0xFFFF


def make_odometer_record(sequence, tenths, remainder):
    data = bytearray(ODOMETER_FRAM_SLOT_SIZE)
    data[0:4] = ODOMETER_FRAM_MAGIC
    data[4:8] = uint32_to_bytes(sequence)
    data[8:12] = uint32_to_bytes(tenths)
    data[12:14] = uint16_to_bytes(remainder)
    data[14:16] = uint16_to_bytes(odometer_checksum(data))
    return data


def parse_odometer_record(data):
    if len(data) != ODOMETER_FRAM_SLOT_SIZE:
        return None
    if bytes(data[0:4]) != ODOMETER_FRAM_MAGIC:
        return None
    expected = bytes_to_uint16(data, 14)
    if odometer_checksum(data) != expected:
        return None
    sequence = bytes_to_uint32(data, 4)
    tenths = bytes_to_uint32(data, 8)
    remainder = bytes_to_uint16(data, 12)
    if remainder >= VSS_PULSES_PER_TENTH_MILE:
        return None
    return {
        "sequence": sequence,
        "tenths": tenths,
        "remainder_pulses": remainder,
    }


class Odometer:
    def __init__(self, fram):
        self.fram = fram
        self.tenths = ODOMETER_START_TENTHS
        self.remainder_pulses = ODOMETER_START_REMAINDER_PULSES
        self.sequence = 0
        self.next_slot = 0
        self.load_ok = False
        self.save_ok = False
        self.last_error = None
        self.last_save_time = 0.0
        self.dirty = False
        self.load()

    def load(self):
        if self.fram is None:
            self.tenths = ODOMETER_START_TENTHS
            self.remainder_pulses = ODOMETER_START_REMAINDER_PULSES
            self.sequence = 0
            self.next_slot = 0
            self.normalize()
            self.load_ok = False
            self.last_error = "FRAM missing"
            return
        try:
            records = []
            for slot_index, slot_address in enumerate(ODOMETER_FRAM_SLOTS):
                data = self.fram.read(slot_address, ODOMETER_FRAM_SLOT_SIZE)
                record = parse_odometer_record(data)
                if record is not None:
                    record["slot_index"] = slot_index
                    records.append(record)
            if not records:
                self.tenths = ODOMETER_START_TENTHS
                self.remainder_pulses = ODOMETER_START_REMAINDER_PULSES
                self.sequence = 0
                self.next_slot = 0
                self.normalize()
                self.load_ok = False
                self.last_error = "no valid FRAM odometer record"
                self.dirty = True
                self.save(time.monotonic())
                return
            latest = records[0]
            for record in records[1:]:
                if record["sequence"] > latest["sequence"]:
                    latest = record
            self.tenths = latest["tenths"]
            self.remainder_pulses = latest["remainder_pulses"]
            self.sequence = latest["sequence"]
            self.next_slot = 1 - latest["slot_index"]
            self.normalize()
            self.load_ok = True
            self.last_error = None
        except Exception as exc:
            self.tenths = ODOMETER_START_TENTHS
            self.remainder_pulses = ODOMETER_START_REMAINDER_PULSES
            self.sequence = 0
            self.next_slot = 0
            self.normalize()
            self.load_ok = False
            self.last_error = str(exc)

    def normalize(self):
        while self.remainder_pulses >= VSS_PULSES_PER_TENTH_MILE:
            self.tenths += 1
            self.remainder_pulses -= VSS_PULSES_PER_TENTH_MILE

    def add_pulses(self, pulse_count):
        if pulse_count <= 0:
            return
        self.remainder_pulses += int(pulse_count)
        self.normalize()
        self.dirty = True

    def miles(self):
        return self.tenths / 10.0

    def formatted(self):
        return "{:07.1f}".format(self.miles())

    def save(self, now):
        if self.fram is None:
            self.save_ok = False
            self.last_error = "FRAM missing"
            return
        try:
            self.sequence = (self.sequence + 1) & 0xFFFFFFFF
            data = make_odometer_record(
                self.sequence,
                int(self.tenths),
                int(self.remainder_pulses),
            )
            self.fram.write(ODOMETER_FRAM_SLOTS[self.next_slot], data)
            self.next_slot = 1 - self.next_slot
            self.save_ok = True
            self.last_error = None
            self.last_save_time = now
            self.dirty = False
        except Exception as exc:
            self.save_ok = False
            self.last_error = str(exc)

    def maybe_periodic_save(self, now, running):
        if not running or not self.dirty:
            return
        if now - self.last_save_time >= ODOMETER_SAVE_INTERVAL_SECONDS:
            self.save(now)

    def snapshot(self):
        return {
            "tenths": self.tenths,
            "remainder_pulses": self.remainder_pulses,
            "miles": self.miles(),
            "load_ok": self.load_ok,
            "save_ok": self.save_ok,
            "last_error": self.last_error,
        }


def bool_text(value):
    if value is None:
        return "--"
    return "HI" if value else "LO"


def active_text(value):
    if value is None:
        return "--"
    return "ON" if value else "off"


def fmt_float(value, places=2):
    if value is None:
        return "--"
    return ("{:." + str(places) + "f}").format(value)


def fmt_int(value):
    if value is None:
        return "--"
    return str(int(value))


def make_label(text, x, y, color=COLOR_TEXT, scale=1):
    return label.Label(terminalio.FONT, text=text, color=color, x=x, y=y, scale=scale)


class TextPage:
    def __init__(self):
        self.group = displayio.Group()
        self.lines = []
        for index in range(14):
            text = make_label("", 4, 9 + index * 17, COLOR_GREEN, 1)
            self.group.append(text)
            self.lines.append(text)

    def set_lines(self, lines):
        for index, text_line in enumerate(self.lines):
            next_text = lines[index] if index < len(lines) else ""
            if text_line.text != next_text:
                text_line.text = next_text
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

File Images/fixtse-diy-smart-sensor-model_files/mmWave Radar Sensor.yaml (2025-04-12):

type: custom:plotly-graph
title: mmWave Radar Sensor
refresh_interval: 1
hours_to_show: current_day
layout:
  height: 230
  margin:
    l: 50
    r: 20
    t: 20
    b: 40
  showlegend: true
  xaxis:
    dtick: 100
    gridcolor: RGBA(200,200,200,0.15)
    zerolinecolor: RGBA(200,200,200,0.15)
    type: number
    fixedrange: true
    range:
      - 400
      - -400
  yaxis:
    dtick: 100
    gridcolor: RGBA(200,200,200,0.15)
    zerolinecolor: RGBA(200,200,200,0.15)
    scaleanchor: x
    scaleratio: 1
    fixedrange: true
    range:
      - 600
      - 0
entities:
  - entity: ''
    name: Target1
    marker:
      size: 12
    line:
      shape: spline
      width: 5
    x:
      - $ex hass.states["sensor.mmwave_sensor_target_1_x"].state /-10
    'y':
      - $ex hass.states["sensor.mmwave_sensor_target_1_y"].state /10
  - entity: ''
    name: Target2
    marker:
      size: 12
    line:
      shape: spline
      width: 5
    x:
      - $ex hass.states["sensor.mmwave_sensor_target_2_x"].state /-10
    'y':
      - $ex hass.states["sensor.mmwave_sensor_target_2_y"].state /10
  - entity: ''
    name: Target3
    marker:
      size: 12
    line:
      shape: spline
      width: 5
    x:
      - $ex hass.states["sensor.mmwave_sensor_target_3_x"].state /-10
    'y':
      - $ex hass.states["sensor.mmwave_sensor_target_3_y"].state /10
  - entity: ''
    name: Zone1
    mode: lines
    fill: toself
    fillcolor: RGBA(20,200,0,0.1)
    line:
      color: RGBA(20,200,0,0.2)
      shape: line
      width: 2
    x:
      - $ex hass.states["number.mmwave_sensor_zone_1_x1"].state /-10
      - $ex hass.states["number.mmwave_sensor_zone_1_x1"].state /-10
      - $ex hass.states["number.mmwave_sensor_zone_1_x2"].state /-10
      - $ex hass.states["number.mmwave_sensor_zone_1_x2"].state /-10
      - $ex hass.states["number.mmwave_sensor_zone_1_x1"].state /-10
    'y':
      - $ex hass.states["number.mmwave_sensor_zone_1_y1"].state /10
      - $ex hass.states["number.mmwave_sensor_zone_1_y2"].state /10
      - $ex hass.states["number.mmwave_sensor_zone_1_y2"].state /10
      - $ex hass.states["number.mmwave_sensor_zone_1_y1"].state /10
      - $ex hass.states["number.mmwave_sensor_zone_1_y1"].state /10
  - entity: ''
    name: Zone2
    mode: lines
    fill: toself
    fillcolor: RGBA(200,0,255,0.1)
    line:
      color: RGBA(200,0,255,0.2)
      shape: line
      width: 2
    x:
      - $ex hass.states["number.mmwave_sensor_zone_2_x1"].state /-10
      - $ex hass.states["number.mmwave_sensor_zone_2_x1"].state /-10
      - $ex hass.states["number.mmwave_sensor_zone_2_x2"].state /-10
      - $ex hass.states["number.mmwave_sensor_zone_2_x2"].state /-10
      - $ex hass.states["number.mmwave_sensor_zone_2_x1"].state /-10
    'y':
      - $ex hass.states["number.mmwave_sensor_zone_2_y1"].state /10
      - $ex hass.states["number.mmwave_sensor_zone_2_y2"].state /10
      - $ex hass.states["number.mmwave_sensor_zone_2_y2"].state /10
      - $ex hass.states["number.mmwave_sensor_zone_2_y1"].state /10
      - $ex hass.states["number.mmwave_sensor_zone_2_y1"].state /10
  - entity: ''
    name: Zone3
    mode: lines
    fill: toself
    fillcolor: RGBA(200,120,55,0.1)
    line:
      color: RGBA(200,120,55,0.2)
      shape: line
      width: 2
    x:
      - $ex hass.states["number.mmwave_sensor_zone_3_x1"].state /-10
      - $ex hass.states["number.mmwave_sensor_zone_3_x1"].state /-10
      - $ex hass.states["number.mmwave_sensor_zone_3_x2"].state /-10
      - $ex hass.states["number.mmwave_sensor_zone_3_x2"].state /-10
      - $ex hass.states["number.mmwave_sensor_zone_3_x1"].state /-10
    'y':
      - $ex hass.states["number.mmwave_sensor_zone_3_y1"].state /10
      - $ex hass.states["number.mmwave_sensor_zone_3_y2"].state /10
      - $ex hass.states["number.mmwave_sensor_zone_3_y2"].state /10
      - $ex hass.states["number.mmwave_sensor_zone_3_y1"].state /10
      - $ex hass.states["number.mmwave_sensor_zone_3_y1"].state /10
  - entity: ''
    name: Coverage
    mode: lines
    fill: tonexty
    fillcolor: rgba(168, 216, 234, 0.15)
    line:
      shape: line
      width: 1
      dash: dot
    x:
      - 0
      - $ex 600 * Math.sin((2 * Math.PI)/360 * 60)
      - 450
      - 400
      - 300
      - 200
      - 100
      - 0
      - -100
      - -200
      - -300
      - -400
      - -450
      - $ex -600 * Math.sin((2 * Math.PI)/360 * 60)
      - 0
    'y':
      - 0
      - $ex 600 * Math.cos((2 * Math.PI)/360 * 60)
      - $ex Math.sqrt( 600**2 - 450**2 )
      - $ex Math.sqrt( 600**2 - 400**2 )
      - $ex Math.sqrt( 600**2 - 300**2 )
      - $ex Math.sqrt( 600**2 - 200**2 )
      - $ex Math.sqrt( 600**2 - 100**2 )
      - 600
      - $ex Math.sqrt( 600**2 - 100**2 )
      - $ex Math.sqrt( 600**2 - 200**2 )
      - $ex Math.sqrt( 600**2 - 300**2 )
      - $ex Math.sqrt( 600**2 - 400**2 )
      - $ex Math.sqrt( 600**2 - 450**2 )
      - $ex 600 * Math.cos((2 * Math.PI)/360 * 60)
      - 0
raw_plotly_config: true

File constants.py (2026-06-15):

#constants.py

import pygame

#   Screen Size
window_width, window_height = 1000, 300
#window_width, window_height = 1920, 720

gauge_window = pygame.display.set_mode((window_width, window_height), pygame.FULLSCREEN)

#gauge_window = pygame.display.set_mode((window_width, window_height), pygame.RESIZABLE)
#test_window = pygame.display.set_mode((400, 400)) #TEMPORARY TRYOUT

#pygame.display.set_caption('Chevrolet K1500')
pygame.display.set_caption('K.I.T.T K1500 Intellegent Truck Technology')

#backGround_image = 'Images/splash2.png'
backGround_image = 'Images/KITT_Splash-09.png'
Icon_image = 'Images/speedometer.png'
Icon = pygame.image.load(Icon_image).convert()
pygame.display.set_icon(Icon)
backGround = pygame.image.load(backGround_image).convert()
backGround = pygame.transform.scale(backGround, (window_width, window_height))

#Temporary to cause indicators to display
indicator_row = 250
illumination_state = False
foglight_state = False
defog_state = False
highbeam_state = False
leftturn_state = False
rightturn_state = False
brakewarn_state = False
oillight_state = False
high4_state = False
mil_state = False
alt_state = False
glow_state = False
speed_status = 55
tach_status = 2000
fuel_status = 73
coolant_status = 90
voltage_status = 14.2
oil_status = 54


#   Colours
NEON_YELLOW = (236, 253, 147)   #   Speedo Colour
NEON_GREEN = (145, 213, 89)     #   Lower gauge colours, clock, odo etc
DARK_GREY = (9, 52, 50)         #   background of the digits (for the 7segment appearance)
GREEN = (0, 255, 0)
BLUE = (0, 175, 255)
AMBER = (255, 191, 0)
TEXTCOLOUR = (255, 255, 255)
TEXTCOLOUR_RED = (255, 0, 0)

#   Font Details
FONT_PATH = "fonts/DSEG7Classic-Bold.ttf"
FONT_LARGE = 90    #   Speedo size
FONT_MEDIUM = 55    #   Clock, MFA, Fuel size
FONT_SMALL = 25     #   Odo Size


#   Locations for gauge graphics, each has the same start XY but builds upon it, check images folder
#RPM_XY = (585, 230)
RPM_XY = (window_width*.585, 230)

#COOLANT_XY = (1481, 105)
#EGT_XY = (1599, 105)
#OILPRESSURE_XY = (60, 25)
#OILPRESSURE_XY = (0, 25)
#BOOST_XY = (1822, 105)
#CLOCK_XY = (555, 620)
#FUEL_XY = (925, 75)
FUEL_XY = (window_width*.925, 75)
#ODO_XY = (60, 644)
#ODO_L_XY = (395, 678)
#MFA_XY = (1435, 668)
#MFABG_XY = (1021, 563)
#SPEEDO_XY = (570 , 55)
SPEEDO_XY = (window_width*.57 , 55)
#COOLANT_XY =(170, 215)
COOLANT_XY =(window_width*.17, 215)
#VOLTAGE_XY = (925, 215)
VOLTAGE_XY = (window_width*.925, 215)
#OIL_XY = (170, 75)
OIL_XY = (window_width*.17, 75)
OIL_LABEL_XY = (60, 25)
COOLANT_LABEL_XY = (40, 162)
#COOLANT_LABEL_XY = (window_width*.4, 162)
VOLTAGE_LABEL_XY = (835, 162)
FUEL_LABEL_XY = (815, 25)
SPEED_LABEL_XY = (560, 10)
TACH_LABEL_XY = (580, 240)
#TACH_LABEL_XY = (window_width/2, 240)

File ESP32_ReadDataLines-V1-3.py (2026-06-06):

import time
import json

import board
import busio
import adafruit_pcf8574
import adafruit_ads1x15.ads1115 as ADS
from adafruit_ads1x15.analog_in import AnalogIn


# ---------- Hardware configuration ----------

# CircuitPython busio.I2C argument order is SCL, SDA.
I2C_SCL = board.IO9
I2C_SDA = board.IO8

PCF1_ADDRESS = 0x20
PCF2_ADDRESS = 0x21
ADS_ADDRESS = 0x48

ADS_ECT_CHANNEL = 0
ADS_OIL_PRESSURE_CHANNEL = 1
ADS_FUEL_LEVEL_CHANNEL = 2

# Update intervals in seconds.
ONE_HZ_INTERVAL = 1.0
TEN_HZ_INTERVAL = 0.1
TWENTY_HZ_INTERVAL = 0.05


# ---------- Sender calibration ----------

SUPPLY_VOLTAGE = 3.3
PULLUP_RESISTOR = 250.0

MAX_SENDER_RESISTANCE = 90.0
MAX_PSI = 80.0

# Replace this with a real ECT sender calibration table or curve.
DEFAULT_ECT_F = 180.0


# ---------- I2C devices ----------

i2c = busio.I2C(I2C_SCL, I2C_SDA)

pcf1 = adafruit_pcf8574.PCF8574(i2c, address=PCF1_ADDRESS)
pcf2 = adafruit_pcf8574.PCF8574(i2c, address=PCF2_ADDRESS)

ads = ADS.ADS1115(i2c, address=ADS_ADDRESS)
ect_raw_v = AnalogIn(ads, ADS_ECT_CHANNEL)
oil_pressure_raw_v = AnalogIn(ads, ADS_OIL_PRESSURE_CHANNEL)
fuel_level_raw_v = AnalogIn(ads, ADS_FUEL_LEVEL_CHANNEL)


# ---------- Digital input map ----------

warning_light_inputs = {
    # Update these names/pins to match the real harness.
    "left_signal": pcf1.get_pin(0),
    "brakewarn": pcf2.get_pin(7),
}

for input_pin in warning_light_inputs.values():
    input_pin.switch_to_input()


dash_state = {
    "fuel_percent": 0,
    "oil_psi": 0,
    "ECT": 0,
    "speed": 0.0,
    "tach": 0,
    "odometer": 153000,
    "left_signal": False,
    "right_signal": False,
    "milwarn": False,
    "illumination": False,
    "foglight": False,
    "high4": False,
    "brakewarn": False,
    "oilwarn": False,
    "altwarn": False,
    "highbeam": False,
}


def clamp(value, minimum, maximum):
    if value < minimum:
        return minimum

    if value > maximum:
        return maximum

    return value


def voltage_to_resistance(vout):
    if vout <= 0:
        return 0.0

    if vout >= SUPPLY_VOLTAGE:
        return MAX_SENDER_RESISTANCE

    return (vout * PULLUP_RESISTOR) / (SUPPLY_VOLTAGE - vout)


def resistance_to_percent(rsensor):
    percent = 100.0 * (1.0 - (rsensor / MAX_SENDER_RESISTANCE))
    return clamp(percent, 0.0, 100.0)


def resistance_to_psi(rsensor):
    psi = MAX_PSI * (1.0 - (rsensor / MAX_SENDER_RESISTANCE))
    return clamp(psi, 0.0, MAX_PSI)


def resistance_to_ect_f(rsensor):
    # Placeholder until the ECT sender resistance/temp curve is known.
    return DEFAULT_ECT_F


def read_speed():
    # Later this would be captured by the ESP32.
    return 70.6


def read_rpm():
    # Later this would be captured by the ESP32.
    return 2800


def read_ect():
    resistance = voltage_to_resistance(ect_raw_v.voltage)
    return resistance_to_ect_f(resistance)


def read_fuel():
    resistance = voltage_to_resistance(fuel_level_raw_v.voltage)
    return resistance_to_percent(resistance)


def read_oil_pressure():
    resistance = voltage_to_resistance(oil_pressure_raw_v.voltage)
    return resistance_to_psi(resistance)


def read_warning_lights():
    lights = {}

    for name, input_pin in warning_light_inputs.items():
        lights[name] = bool(input_pin.value)

    return lights


def update_warning_lights():
    lights = read_warning_lights()

    for name, value in lights.items():
        dash_state[name] = value


def send_dash_state():
    print(json.dumps(dash_state))


last_fuel_time = 0
last_oil_time = 0
last_light_time = 0
last_send_time = 0
last_ect_time = 0
last_mph_time = 0
last_tach_time = 0
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

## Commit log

2025-04-12 Initial project version 0.2
    [base.stl, body.stl, body_light_temperature.stl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]
2026-06-06 Fix fuel oil and ECT sensor calibration
    [31.py, ESP32_ReadDataLines-V1-3.py, code.py]
2026-06-07 Reversed commented out debug timeing codes
    [code.py]
2026-06-07 Add ESP32 instrument cluster baseline
2026-06-07 Show FRAM init error on system page
    [code.py]
2026-06-07 Fix FRAM read probe on CircuitPython I2C
    [code.py]
